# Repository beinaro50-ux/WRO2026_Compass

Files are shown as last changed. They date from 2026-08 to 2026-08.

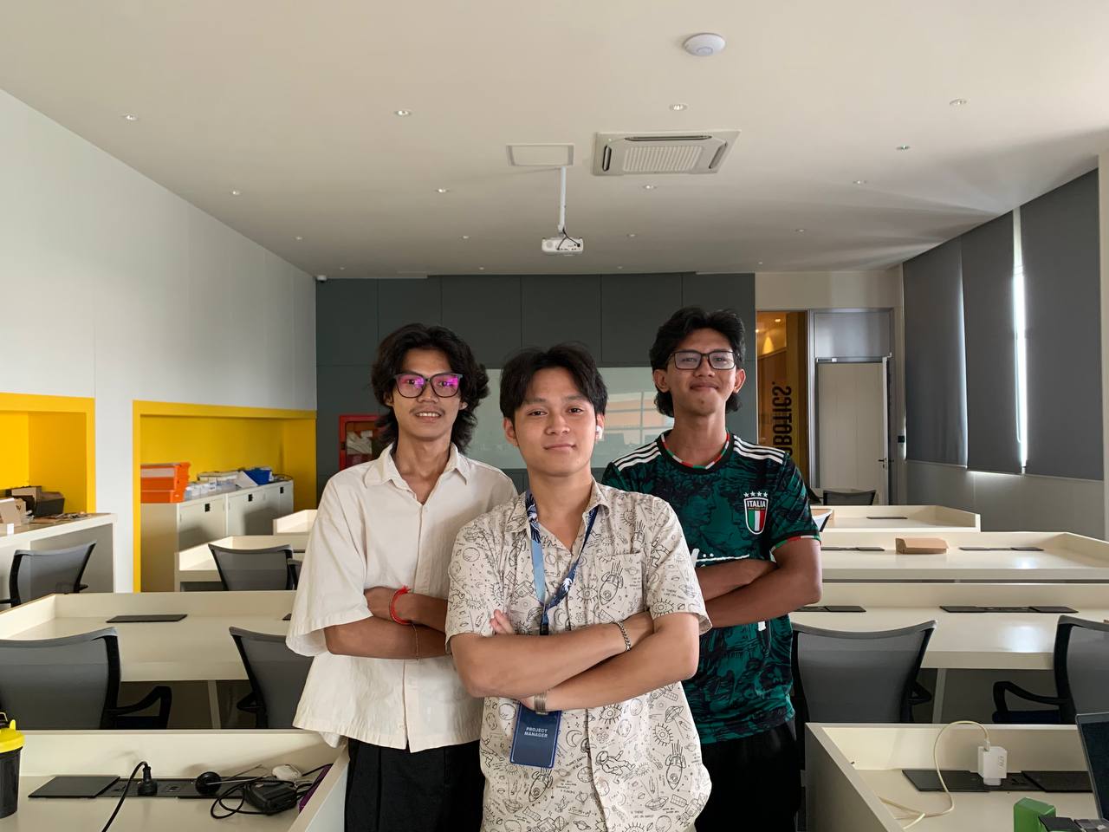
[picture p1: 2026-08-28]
Photo Robot & Team/photo_2026-08-28_14-54-29.jpg

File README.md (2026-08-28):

w# WRO2026_Compass
# Team Compass — WRO 2026 Future Engineers: Self-Driving Cars Challenge

**Country:** Cambodia
**Team Members:** Be Naro, Yeong Vechakasy Sothon, Art Oudom
**Coach:** Taing Liv Min

**GitHub Repository:** `[ TBD — add before the 3-weeks-before-competition submission deadline ]`
**Open Challenge Video:** `[ TBD ]`
**Obstacle Challenge Video:** `[ TBD ]`

---

## Table of Contents
1. [Mobility and Mechanical Design](#1-mobility-and-mechanical-design)
2. [Power and Sensor Architecture](#2-power-and-sensor-architecture)
3. [Software Architecture and Obstacle Strategy](#3-software-architecture-and-obstacle-strategy)
4. [Systems Thinking and Engineering Decisions](#4-systems-thinking-and-engineering-decisions)
5. [Reproducibility and Repository Structure](#5-reproducibility-and-repository-structure)
6. [Photos and Video Demonstrations](#6-photos-and-video-demonstrations)

---

## 1. Mobility and Mechanical Design

### 1.1 Chassis and Drive System
Our chassis is fully **3D-printed in PLA filament**, designed to fit within the 300 × 200 × 300 mm vehicle envelope required by WRO rule 11.1.

The drivetrain is **rear-wheel drive (RWD)**, powered by a single **JGA25-370 DC gear motor** (12V, rated 1360 RPM), driving the rear axle through a two-stage gear reduction:
- A 14 mm pinion gear on the motor output meshes with a 25 mm gear on the driven axle
- This gives an approximate **1.79:1 reduction**

This gearing trades top speed for extra torque and steadier low-speed control, which matters for precise lane-following and parking maneuvers.

### 1.2 Steering Mechanism
Steering is handled by a single **MG996R servo** connected to a steering linkage on the front axle, satisfying WRO rule 11.3 (one steering actuator, front/rear/4WD drive — not a differential/skid-steer base).

| Parameter | Value |
|---|---|
| Length from servo to wheel connector | 75 mm |
| Maximum steering angle | 30° |
| Radius | 75 mm |
| Diameter | 150 mm |
| Turning length (AB) | 39.25 mm |

### 1.3 Diagrams / CAD Views
Robot 


Front side


Back side


Bottom 


### 1.4 Testing and Iteration
We went through **three major chassis redesigns** before arriving at our current layout:

- **Versions 1 & 2:** Placed the RPLiDAR A2M12 at the rear of the vehicle. Limited internal space made it difficult to route wiring and mount the ESP32, L298N driver, and battery cleanly.
- **Version 3 (current):** Relocated the LiDAR to the front of the vehicle and moved the ESP32, motor driver, and battery to the rear. This freed up space around the LiDAR's 360° scanning field and simplified our wiring harness.

We also **raised the camera's mounting height** after early testing showed our original (lower) mounting position caused the camera to miss or misjudge the distance to obstacle pillars. Raising the mount improved our ability to keep pillars clearly framed for detection.

---

## 2. Power and Sensor Architecture

### 2.1 Power System
The vehicle uses a single **12V 3A battery pack** as the primary power source, feeding the ESP32, the DC motor (via the L298N driver), and the steering servo. The servo line is stepped down from 12V through a regulator/transformer before reaching the MG996R (rated 4.8–7.2V).

The **Raspberry Pi 4 is powered independently** from a separate portable USB power bank, isolating its 5V logic supply from motor and servo electrical noise on the 12V line.

### 2.2 Power Budget

| Component | Voltage | Est. Current | Source |
|---|---|---|---|
| Raspberry Pi 4 | 5V (power bank) | ~3A max | Official RPi4 PSU rating |
| ESP32 | 5V (onboard reg.) | ~0.3–0.5A typical | Datasheet typical |
| RPLiDAR A2M12 | 5V | ~0.2–0.3A (core+motor) | Manufacturer spec |
| JGA25-370 DC Motor | 12V | ~0.3A run / ~3A stall | Typical for motor class |
| MG996R Servo | 9V | ~0.5–0.9A / ~2.5A stall | Datasheet typical |

> **Note:** These are datasheet/spec estimates, not yet measured on this specific build. Actual draw should be measured with a multimeter or USB power meter (especially motor and servo under load/stall) before finalizing wiring gauge and battery sizing.

### 2.3 Sensor Suite
- **RPLiDAR A2M12** (360°, 12 m range) — mounted front-facing, providing wall-distance and obstacle-range data used for LiDAR-based wall following.
- **USB webcam (8 MP)** — mounted toward the back of the chassis on a camera stand. Used for pillar color/class detection and lane-position estimation via our trained YOLO model.

### 2.4 Wiring Diagram
The vehicle's electrical system is split into four subsystems on two isolated power domains: a 5V logic/compute domain (Raspberry Pi 4 + sensors) and a 12V power domain (drive motor + servo), bridged by the ESP32 acting as the real-time actuator controller.
Subsystem 1 — Central Control & Vision (5V)
- A dedicated 5V powerbank supplies the Raspberry Pi 4 via USB 3.0 (rated ~3A max draw).
- The USB 2.0 8MP PC camera connects to the Pi 4 via USB 3.0.
- The RPLiDAR A2M12 (5V, ~0.2–0.3A) connects to the Pi 4 via USB.
- This subsystem is intentionally powered independently from the 12V motor/servo domain, isolating the Pi's logic supply from motor electrical noise.
Subsystem 2 — Actuator Control (ESP32). 
- The Raspberry Pi 4 communicates with the ESP32 over a serial link (Tx/Rx), sending high-level driving commands.
- The ESP32 runs on its onboard 5V regulator (~0.3–0.5A).
- The ESP32 outputs: 
  **PWM + H-bridge control signals to the L298N motor driver (Subsystem 3)**
  **PWM signal to the MG996R servo (Subsystem 4)**
  **Shared GND to both subsystems**
  Subsystem 3 — L298N DC Motor Driver (12V high-power)
- A 12V 3A battery feeds the L298N driver board directly ("12V Battery Input").
- The JGA25-370 DC motor connects to the L298N's Motor A output terminals.
- The ESP32 sends a PWM signal (IN1) to the L298N to control motor speed/direction.
- The L298N also exposes a 12V output tap, which is routed onward to Subsystem 4's power converter.
  Subsystem 4 — Servo Subsystem
- The L298N's 12V output feeds a power converter (12V in → 9V out), which steps the battery voltage down to a safe level for the MG996R servo (rated 4.8–7.2V nominal, but run here at ~9V converted power per your table).
- The servo receives PWM control from the ESP32 and shares GND across the system.
- Current draw reference from your spec table: ~0.33A running at 12V, ~0.5–0.9A running at 9V, up to ~2.5A stall.

### 2.5 Calibration
*[ Describe sensor calibration — e.g., camera color thresholds for red/green pillar detection, LiDAR mounting angle offset — once finalized ]*

---

## 3. Software Architecture and Obstacle Strategy

### 3.1 System Architecture
Our software runs on the **Raspberry Pi 4** and is organized into cooperating modules:

- **LiDAR reader** — background thread continuously reading the RPLiDAR A2M12
- **Vision worker** — camera capture plus YOLO model inference
- **State machine** — fuses LiDAR wall-following with camera-based pillar and lane detection to decide speed and steering
- **Serial link** — sends the resulting commands to the ESP32, which drives the DC motor (via L298N) and steering servo in real time

**Flowchart**


### 3.2 Lane Following Strategy
Our primary lane-following signal comes from the **RPLiDAR A2M12**: we calculate the vehicle's distance to the left and right walls from the 360° scan and use a **PID controller** to steer toward the section centerline.

Camera-based lane detection from our YOLO model is layered on top as a **secondary correction signal**, since LiDAR is more robust to lighting changes on the track than a camera alone.

### 3.3 Obstacle (Traffic Sign) Strategy
Our team designed the vehicle's mechanical layout in **Solid Edge** and trained our pillar/lane detection model using **YOLO**. The model detects red and green traffic pillars in the camera frame and classifies them by color.

Per WRO rule 9.19:
- When a **red pillar** is detected ahead, the vehicle steers to keep the pillar on its **right** side.
- When a **green pillar** is detected, the vehicle steers to keep the pillar on its **left** side.

**To be completed before submission:**
- Final training image count and train/validation split
- Key metrics (e.g., mAP, precision/recall)
- PID tuning notes for the wall-following controller, based on physical track testing

## 4. Systems Thinking and Engineering Decisions

### 4.1 Subsystem Interaction Map


That maps how your four subsystems depend on each other: Power feeds all three others directly (amber arrows), Sensors feed raw LiDAR + camera data into Software, and Software sends the final steering/motor commands down to Mobility.

This is the kind of diagram Appendix C Criterion 4 ("Systems Thinking") specifically rewards — it shows you understand the robot as an interconnected system rather than just a parts list. A couple of notes for when you drop this into the README:

- If you want to be even more precise, you could split the single "Power" arrow into three separately-labeled ones (5V line to Pi/sensors, 12V line to motor, 9V converted line to servo) — that would tie directly back into your power budget table and reinforce the two-domain design you documented.
- This diagram pairs well with the ground-domain risk we discussed earlier — you could add a small dashed line or note showing "no shared ground (current risk)" between the Power and Mobility boxes if you want the diagram itself to visually flag that gap, not just the prose.

### 4.2 Key Design Tradeoffs

**Decision 1 — Sensor placement vs. available chassis space:**
Our first two chassis revisions placed the RPLiDAR at the rear of the vehicle, but tight internal space made wiring and component mounting difficult. We chose to redesign (third iteration) and move the LiDAR to the front, trading some rear layout simplicity for a cleaner wiring harness and an unobstructed 360° scan field.

**Decision 2 — ONNX vs. PyTorch for on-board inference:**
Our trained model was exported in both PyTorch (`.pt`) and ONNX (`.onnx`) formats. We chose to deploy the **ONNX** version on the Raspberry Pi 4, since ONNX Runtime is significantly faster and lighter-weight for inference on limited onboard compute than running the full PyTorch framework — this matters for keeping our control loop running at a consistent rate during a live round.

### 4.3 Risks and Mitigations

| Risk | Mitigation |
|---|---|
| Serial link between RPi4 and ESP32 drops mid-run | ESP32 firmware includes a watchdog timer that force-stops the motor if no command is received within 300ms |
| Servo over-voltage (MG996R rated 4.8–7.2V, battery is 12V) | Servo power is stepped down through a separate regulator before reaching the servo (exact output voltage to be confirmed and documented) |
| Camera mounted too low to reliably detect pillars | Identified during testing; camera mount height was raised in our third chassis revision |
| Limited internal chassis space causing wiring/component conflicts | Redesigned chassis three times, relocating LiDAR to the front and ESP32/motor driver/battery to the rear |

### 4.4 Version History
- **Version 1:** Initial chassis with LiDAR mounted at the rear — space too tight for clean wiring.
- **Version 2:** Adjusted internal layout, LiDAR remained at the rear — still constrained; camera mounted too low for reliable pillar detection.
- **Version 3 (current):** LiDAR relocated to the front; ESP32, L298N, and battery relocated to the rear; camera mount height raised.

We are going to fix some of this robot machinal due to it contains some stress from steering wheel and the battery do not have enough power to 

---

## 5. Reproducibility and Repository Structure

### 5.1 Planned Repository Layout

```
/src              — vehicle control source code
                    (main.py, config.py, lidar_module.py,
                     vision_module.py, state_machine.py, serial_link.py)
/esp32_firmware   — ESP32 motor/servo controller firmware
/models           — trained YOLO model files (ONNX export used on-vehicle)
/cad              — 3D-printable chassis files
/schematics       — wiring diagrams, power budget
/media            — vehicle photos (6 views) and team photo
```

> **Status:** Repository is not yet public. Per WRO rules, we will follow the required commit timing (first commit ≥ 2 months before competition containing at least 1/5 of final code, second ≥ 1 month before, third ≥ 2 weeks before) and add the public URL above before the submission deadline (3 weeks before competition).

### 5.2 Build Instructions Summary
**Software section** 
We use a pretrained YOLO model (not custom-trained on our own pillar dataset) rather than collecting and labeling our own training set. Our own engineering work here was in configuring the model's confidence threshold — tuning the minimum detection confidence YOLO needs before we trust a detection, to balance:

Missed detections (threshold too high → pillar not seen in time to react)
False positives (threshold too low → reacting to noise or irrelevant objects)

Why we chose this approach over training our own model:
Training a custom YOLO model requires collecting and labeling a large dataset of red/green pillar images across different lighting conditions, distances, and angles — a significant time investment. Using a pretrained model with tuned thresholds let us get a working detection pipeline running quickly at the tradeoff of relying on YOLO's general-purpose object classes rather than a model purpose-built to recognize WRO pillars specifically.

To be completed before submission:

The exact confidence threshold value we settled on, and the reasoning/testing behind it (e.g., "we tested 0.5, 0.6, 0.7 and found 0.6 gave the best balance of X vs Y")
How color (red vs. green) is actually determined once YOLO flags a detection — e.g., pixel-color sampling within the bounding box (this connects to your calibration section, which is also still pending)
Any measured detection accuracy/reliability from track testing

**Hardware Section**
The mechanical design phase took approximately two weeks, followed by roughly nine days of physical assembly.

A key challenge emerged during this process: our initial chassis design was built to accommodate only three hardware components. Partway through assembly, some of those original components broke and had to be replaced with larger alternatives — which no longer fit within the space our first design had allocated. This forced us to revisit our internal layout and rework the chassis to accommodate the new component sizes, rather than simply swapping parts in place.

This experience directly informed our decision to design for extra internal clearance in later chassis revisions (see Version History, Section 4.4), rather than sizing the chassis tightly around the exact components on hand — a lesson that also shaped our approach to component selection going forward, favoring some margin for hardware substitutions over a minimal-footprint design.

## 6. Photos and Video Demonstrations

### 6.1 Required Photos
- Team photo
  
  
- Front side
  
- Back Side
  
- Above
  
- Bottom
  
- Left Side
  
- Right Side
  

### 6.2 Video Demonstrations
Per WRO documentation rules, one YouTube video (public or unlisted/link-accessible) is required for **each** challenge, with a driving demonstration segment at least 30 seconds long.

- **Open Challenge video:** `
https://youtu.be/FjARO7ldRJU

- **Obstacle Challenge video:** `
https://youtu.be/bZQAO0thAtA

---

*This documentation follows the WRO 2026 Future Engineers General Rules, Section 7 (Engineer's Documentation on GitHub) and Appendix C (Engineering Journal Evaluation).*

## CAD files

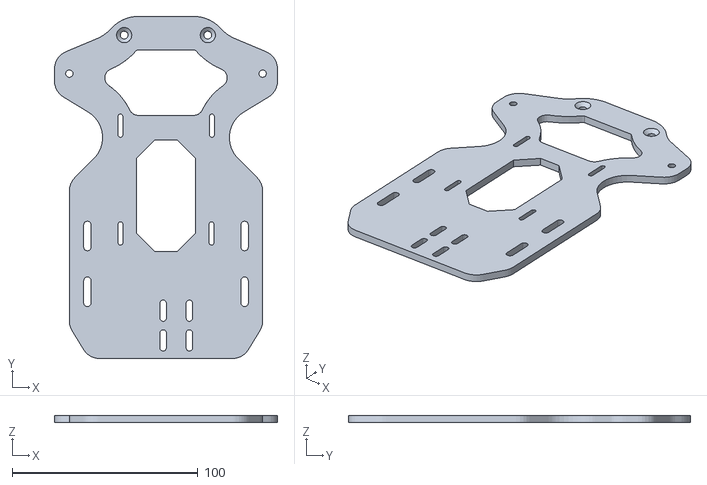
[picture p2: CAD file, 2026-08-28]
Model/Chassis 1st floor.stl
120.0 x 184.0 x 4.00

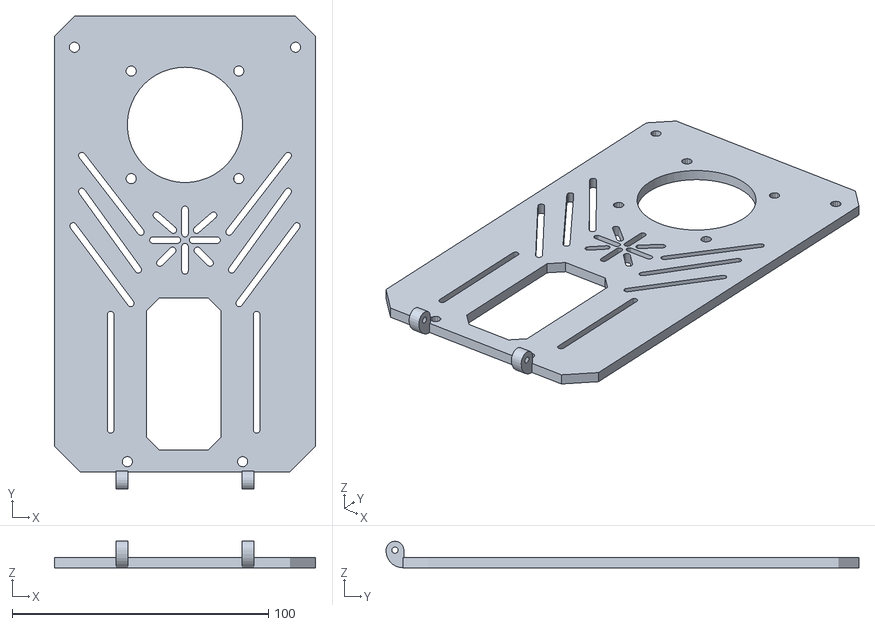
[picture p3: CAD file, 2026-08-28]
Model/Platform 3rd floor .stl
102.0 x 184.7 x 10.4

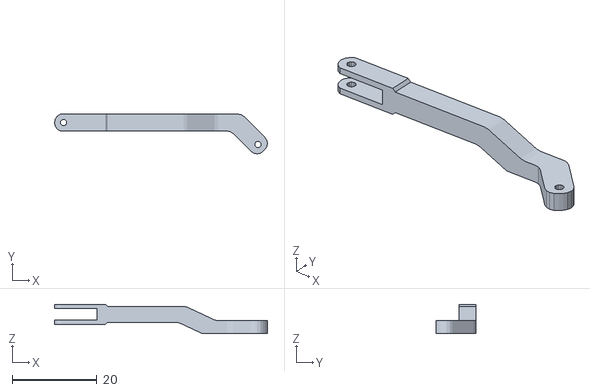
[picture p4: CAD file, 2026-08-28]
Model/Steering wheel (left).stl
50.2 x 9.37 x 6.95

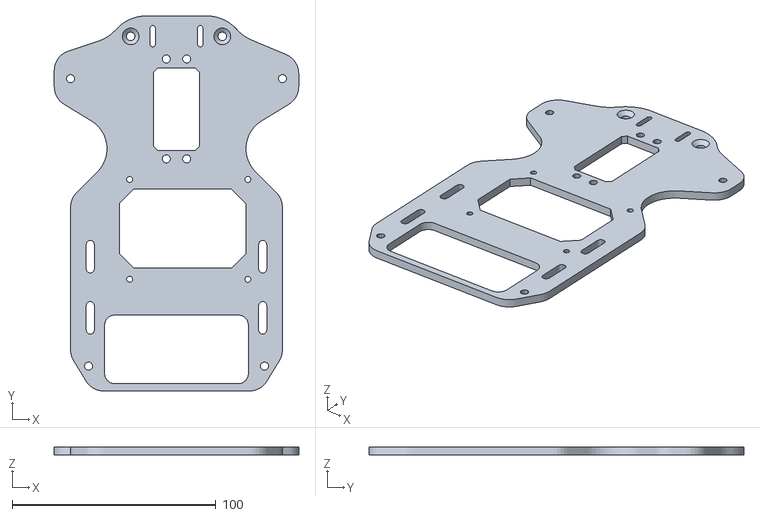
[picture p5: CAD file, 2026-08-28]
Model/Chassis 2rd floor.stl
120.0 x 184.0 x 4.00

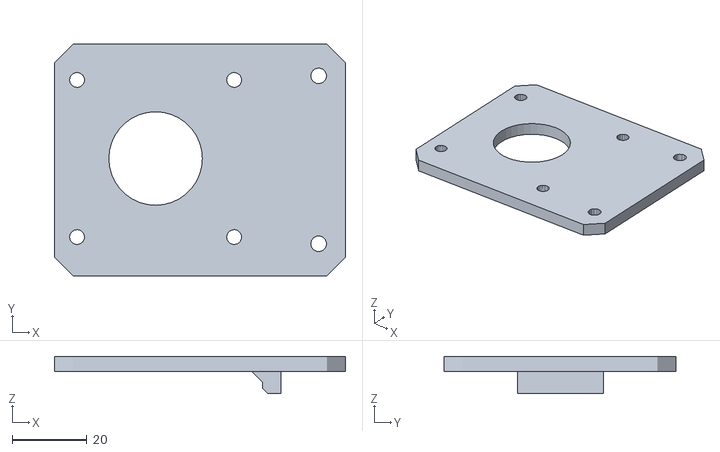
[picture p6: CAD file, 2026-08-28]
Model/RPLidar platform.stl
77.8 x 62.0 x 10.0

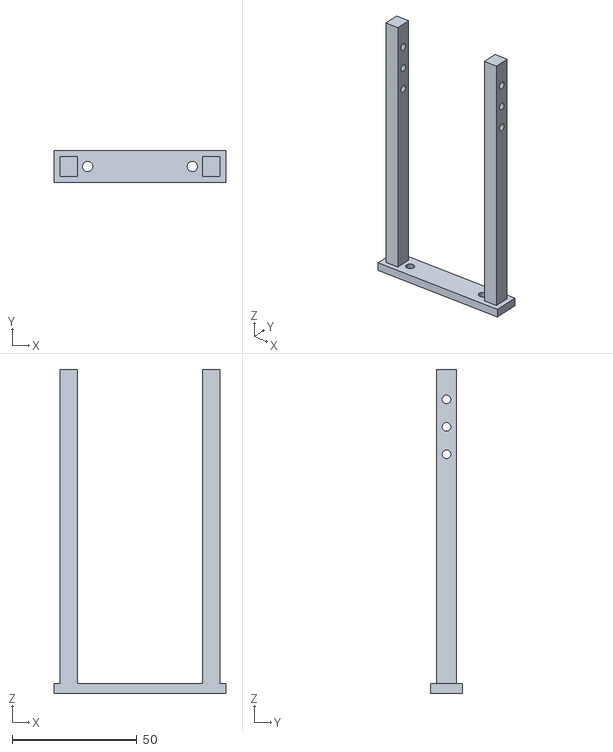
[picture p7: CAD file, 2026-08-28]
Model/camerastanding.stl
69.0 x 13.0 x 130.0

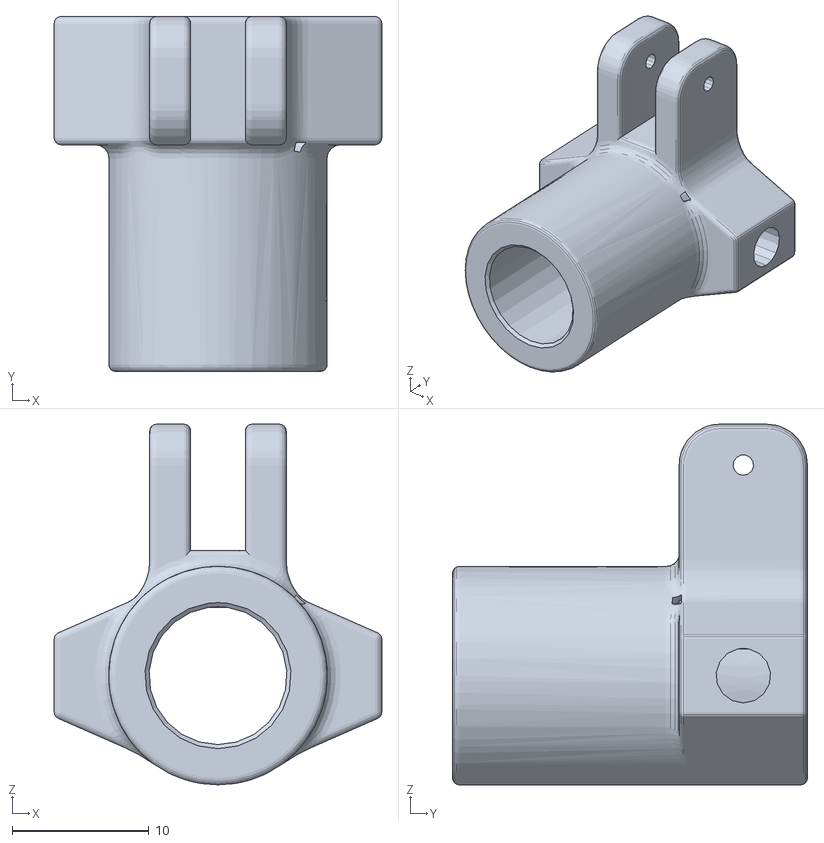
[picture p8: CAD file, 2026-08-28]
Model/Hub.stl
24.0 x 26.0 x 26.4

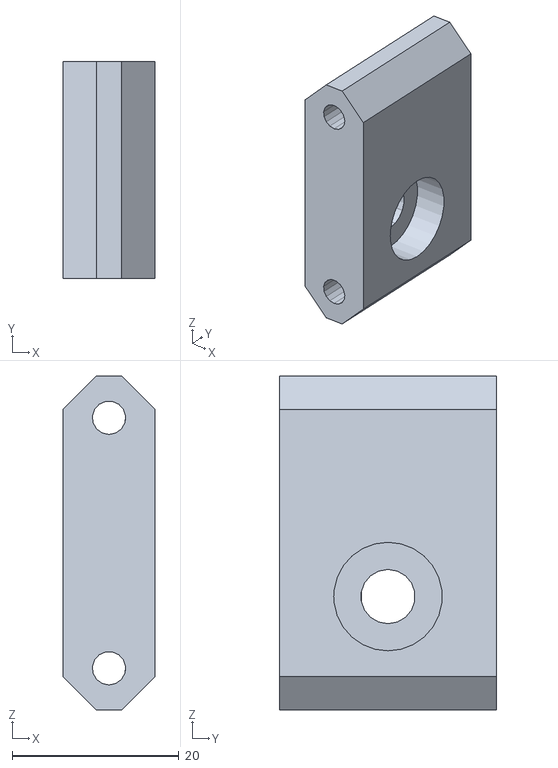
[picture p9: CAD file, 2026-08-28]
Model/BackWheel Mount.stl
11.0 x 26.0 x 40.0

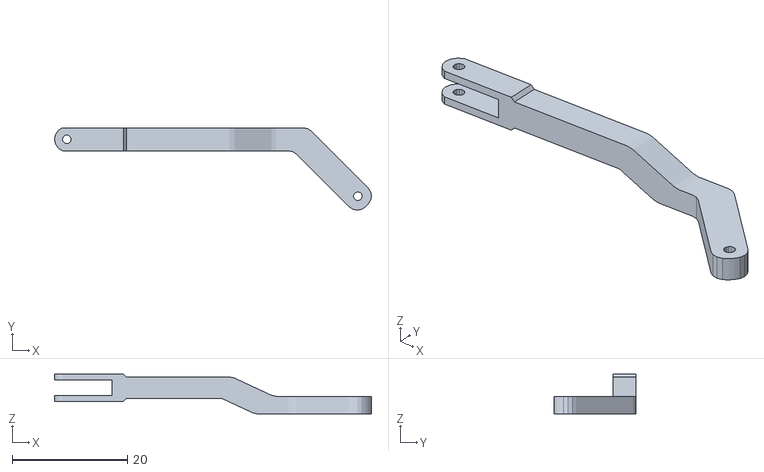
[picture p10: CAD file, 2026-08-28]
Model/Steering wheel (right).stl
55.1 x 14.3 x 6.95

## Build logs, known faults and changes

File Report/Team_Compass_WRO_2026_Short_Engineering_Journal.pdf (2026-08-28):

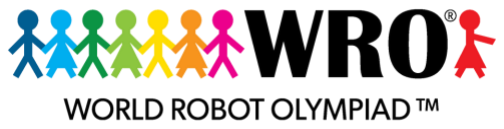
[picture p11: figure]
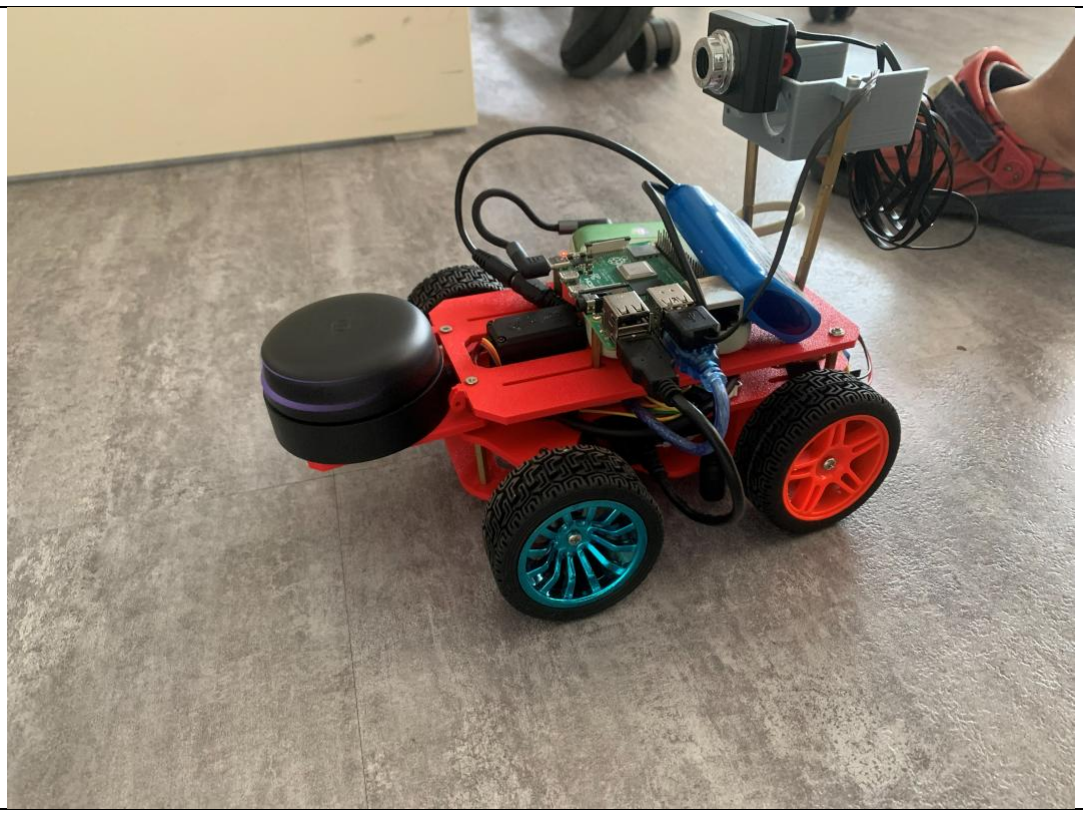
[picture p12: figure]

Team Compass | WRO 2026 Future Engineers
Team name | Compass
Team number | FE-002
Team members | Be Naro, Yeong Vechakasy Sothon, Art Oudom
Team coach | Taing Ly Min
Robotic set | Self-assembled set
Weight | 1.10kg
Size | 290× 175 × 180 mm
Building materials | Fully 3D-printed PLA chassis and mechanical parts
Controllers | Raspberry Pi 4, ESP32, L298N
Battery | 12V, 3A battery pack; Raspberry Pi 4 uses separate USB power bank
Sensors | 1× RPLiDAR A2M12, 1× 8 MP USB webcam
Motors | 1× JGA25-370 DC gear motor, 1× MG996R servo
Pneumatic system | Not used
Spare parts | Battery x3, Battery charger x2, Screw driver set, Nuts x5, glue stick x1, power bank x1,
Programming Environment & language | Python, YOLO, ESP32 firmware
Drive & steering | RWD; single MG996R front steering servo; max steering angle 30°
Gear reduction | 14 mm pinion → 25 mm gear; ≈1.79:1 reduction
Steering geometry | 75 mm radius; 150 mm diameter; AB = 39.25 mm
Design iteration | 3 chassis designs; LiDAR moved rear → front; electronics/battery moved to rear; camera mount raised after testing
LiDAR function | 360° wall-distance and obstacle detection; primary lane/wall-following signal
Camera function | YOLO detects red/green pillars and provides secondary lane-position correction
Control algorithm | PID lane following + state machine combining LiDAR and vision
Red pillar | Keep pillar on the right
Green pillar | Keep pillar on the left
GitHub / Videos | https://youtu.be/hSMSpn8qdMk

Picture of the robot with start and stop bottom

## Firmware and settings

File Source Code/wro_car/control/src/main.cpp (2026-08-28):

#include <Arduino.h>

// Motor
#define IN1 26
#define IN2 27
#define ENA 25
#define MOTOR_CHANNEL 0
#define MOTOR_FREQ 5000
#define MOTOR_RES 8
#define PWM_MIN 150
#define PWM_MAX 255

// Servo (manual PWM, no library, separate channel/timer from motor)
#define SERVO_PIN 19
#define SERVO_CHANNEL 4
#define SERVO_FREQ 50
#define SERVO_RES 16
#define SERVO_MIN_US 500
#define SERVO_MAX_US 2500

// Encoder
#define ENC_A 34
#define ENC_B 35

volatile long encoderTicks = 0;
void IRAM_ATTR encoderISR() {
  int a = digitalRead(ENC_A);
  int b = digitalRead(ENC_B);
  encoderTicks += (a == b) ? 1 : -1;
}

String inputBuffer = "";
unsigned long lastFeedback = 0;
const unsigned long FEEDBACK_INTERVAL_MS = 50;

void motorStop() {
  digitalWrite(IN1, LOW);
  digitalWrite(IN2, LOW);
  ledcWrite(MOTOR_CHANNEL, 0);
}

void setMotor(int throttle) {
  throttle = constrain(throttle, -255, 255);
  if (throttle == 0) { motorStop(); return; }
  int mag = abs(throttle);
  int pwm = constrain(map(mag, 1, 255, PWM_MIN, PWM_MAX), PWM_MIN, PWM_MAX);
  if (throttle > 0) { digitalWrite(IN1, HIGH); digitalWrite(IN2, LOW); }
  else              { digitalWrite(IN1, LOW);  digitalWrite(IN2, HIGH); }
  ledcWrite(MOTOR_CHANNEL, pwm);
}

void setServoAngle(int angle) {
  angle = constrain(angle, 0, 360);
  int pulse_us = map(angle, 0, 360, SERVO_MIN_US, SERVO_MAX_US);
  uint32_t maxDuty = (1UL << SERVO_RES) - 1;
  uint32_t duty = (uint32_t)(((float)pulse_us / 20000.0f) * maxDuty);
  ledcWrite(SERVO_CHANNEL, duty);
}

void processCommand(String cmd) {
  cmd.trim();
  if (cmd.length() < 3) return;
  char type = cmd.charAt(0);
  String value = cmd.substring(2);

  if (type == 'M') {
    int throttle = value.toInt();
    setMotor(throttle);
    Serial.print("AM,"); Serial.println(throttle);
  } else if (type == 'S') {
    int angle = value.toInt();
    setServoAngle(angle);
    Serial.print("AS,"); Serial.println(angle);
  }
}

void setup() {
  Serial.begin(115200);

  pinMode(IN1, OUTPUT);
  pinMode(IN2, OUTPUT);
  ledcSetup(MOTOR_CHANNEL, MOTOR_FREQ, MOTOR_RES);
  ledcAttachPin(ENA, MOTOR_CHANNEL);

  ledcSetup(SERVO_CHANNEL, SERVO_FREQ, SERVO_RES);
  ledcAttachPin(SERVO_PIN, SERVO_CHANNEL);
  setServoAngle(90);

  pinMode(ENC_A, INPUT);
  pinMode(ENC_B, INPUT);
  attachInterrupt(digitalPinToInterrupt(ENC_A), encoderISR, CHANGE);

  motorStop();
  Serial.println("READY");
}

void loop() {
  while (Serial.available() > 0) {
    char c = Serial.read();
    if (c == '\n') { processCommand(inputBuffer); inputBuffer = ""; }
    else inputBuffer += c;
  }

  unsigned long now = millis();
  if (now - lastFeedback >= FEEDBACK_INTERVAL_MS) {
    lastFeedback = now;
    Serial.print("ENC,");
    Serial.println(encoderTicks);
  }
}

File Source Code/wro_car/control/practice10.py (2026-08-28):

#!/usr/bin/env python3
"""
WRO Future Engineers 2026 - Bench Test & Teleop Dashboard
=========================================================
"""
import argparse
import json
import logging
import math
import os
import threading
import time
from dataclasses import dataclass, field

# Keep the BLAS libraries single-threaded. numpy/OpenCV spawning their own
# thread pools on top of our threads is a common source of instability and
# jitter on a Raspberry Pi. Must be set before numpy/cv2 are imported.
os.environ.setdefault("OPENBLAS_NUM_THREADS", "1")
os.environ.setdefault("OMP_NUM_THREADS", "1")
os.environ.setdefault("MKL_NUM_THREADS", "1")
os.environ.setdefault("NUMEXPR_NUM_THREADS", "1")
os.environ.setdefault("OPENCV_LOG_LEVEL", "ERROR")

import cv2
import numpy as np
import flask.cli
from flask import Flask, Response, jsonify, render_template_string, request

# cv2.dnn's forward pass otherwise grabs every core in its own thread pool for
# the duration of each inference call. On the Pi 4B's 4 cores that starves the
# LiDAR thread of scheduling time long enough for the OS serial buffer to
# overflow ("Too many bytes in the input buffer ... Cleaning buffer"), forcing
# an RPLidar rescan. Leaving 1-2 cores free keeps that thread - and the camera
# capture thread and the Flask dashboard - responsive while inference runs.
cv2.setNumThreads(2)

# ============================================================================
# SECTION 1 - TUNABLE PARAMETERS
# ============================================================================

# ---------------------------------------------------------------- 1.1 chassis
WHEELBASE_MM = 125.0             # front axle centre to rear axle centre
FRONT_TRACK_MM = 140.0           # left to right front wheel centre
REAR_TRACK_MM = 125.0            # left to right rear wheel centre
WHEEL_DIAMETER_MM = 68.0         # measured with the tyre fitted, not the rim
ROBOT_LENGTH_MM = 250.0          # used only to sanity-check rule 11.1 / 9.17
ROBOT_WIDTH_MM = 170.0           # limit is 300 x 200 mm, height 300 mm

# ------------------------------------------------------- 1.2 steering servo
STEER_CENTRE_CMD = 100           # servo command that points the wheels straight
STEER_CMD_MIN = -140                # servo command at full left lock
STEER_CMD_MAX = 140              # servo command at full right lock
STEER_MAX_LEFT_DEG = 30.0        # MEASURE: real wheel angle at full left
STEER_MAX_RIGHT_DEG = 30.0        # MEASURE: real wheel angle at full right

# ---------------------------------------------------------- 1.3 drive motor
DRIVE_CMD_MAX = 255              # ESP32 accepts -255..255
TICKS_PER_WHEEL_REV = 2000       # MEASURE: roll the wheel 10 turns by hand,
THROTTLE_POLARITY = -1           # set to -1 if a positive command drives the
                                 # car backwards. Applied only in set_drive(),

# Slew-rate limits.
THROTTLE_RAMP_PER_SEC = 400.0    # throttle units per second (0->255 in ~0.6 s)
STEER_RAMP_PER_SEC = 180.0       # degrees per second
RAMP_LOOP_HZ = 50                # how often the ramp loop ticks

# ----------------------------------------------------------- 1.4 serial link
SERIAL_PORT = "/dev/esp32"       # or COM5 on Windows
SERIAL_BAUD = 115200
SERIAL_RECONNECT_SEC = 2.0
COMMAND_WATCHDOG_SEC = 0.5       # stop the motor if no command arrives in time

# ---------------------------------------------------------------- 1.5 camera
# "/dev/webcam" is a stable symlink, not a real device - create it with a udev
# rule keyed to the webcam's vendor:product ID so it does not move to
# /dev/video1 after a reboot or a different USB port. Numeric index 0 also
# works but is not reliable once a second camera or capture device is plugged
# in.
CAMERA_DEVICE = "/dev/webcam"    # or an integer index such as 0
FRAME_WIDTH = 640
FRAME_HEIGHT = 480               # a mini USB 2.0 webcam is usually MJPG-only
                                 # at this size; raw YUYV caps out near 5 fps
JPEG_QUALITY = 70                # lower = less WiFi bandwidth on the Pi

CAMERA_HEIGHT_MM = 160.0         # lens centre above the mat
CAMERA_TILT_DEG = 0.0            # positive = tilted down toward the mat
CAMERA_FOCAL_PX = 600.0          # pinhole focal length in pixels

# ------------------------------------------------------- 1.6 pillar geometry
PILLAR_WIDTH_MM = 50             # rule 13.19: 50 x 50 x 100 mm
PILLAR_HEIGHT_MM = 100
PILLAR_ASPECT_NOMINAL = PILLAR_WIDTH_MM / PILLAR_HEIGHT_MM   # 0.5

# ------------------------------------------------------ 1.7 detection backend
DETECTION_BACKEND = "auto"

# ---------------------------------------------------------- 1.8 ONNX detector
# Resolved next to this script, not the process's working directory, so this
# still finds best.onnx when launched by a systemd service or a start button
# instead of a manually cd'ed-into terminal (rule 9.10 / 9.11).
ONNX_MODEL_PATH = os.path.join(os.path.dirname(os.path.abspath(__file__)), "best.onnx")
ONNX_INPUT_SIZE = 416            # confirmed from best.onnx's own input tensor
                                 # (images: [1,3,416,416]) - must always match
                                 # whatever imgsz a re-export uses
ONNX_CONF_THRESHOLD = 0.45
ONNX_NMS_IOU_THRESHOLD = 0.45
# Detection runs on its own thread at whatever pace inference allows (see
# Camera._detect_loop) rather than every Nth captured frame, so the video
# stream never stalls waiting for a slow forward pass.
ONNX_CLASS_NAMES = ["greenbox", "redbox", "xparking"]
CLASS_NAME_TO_COLOUR = {
    "greenbox": "GREEN",
    "redbox": "RED",
}

# ----------------------------------------------------------- 1.9 HSV detector
# Minimum value (brightness) set to 100 to completely block black walls!
HSV_RED_RANGES = [((0, 120, 100), (10, 255, 255)), ((170, 120, 100), (179, 255, 255))]
HSV_GREEN_RANGE = ((40, 120, 100), (85, 255, 255))
HSV_MORPH_KERNEL = 5             # noise clean-up kernel, odd numbers only
HSV_MIN_AREA_PX = 300            # reject specks
HSV_MAX_AREA_PX = 150000         # INCREASED: detect closer/larger boxes
HSV_MIN_ASPECT = 0.25            # a pillar is 0.5 wide/high; allow for angle
HSV_MAX_ASPECT = 0.90
RULEBOOK_RED_RGB = (238, 39, 55)
RULEBOOK_GREEN_RGB = (68, 214, 44)

# ----------------------------------------------------------------- 1.10 LiDAR
LIDAR_PORT = "/dev/rplidar"
LIDAR_BAUD = 256000              # RPLidar A2M12 default
LIDAR_HEIGHT_MM = 80.0           # mounted at the nose of the chassis
LIDAR_RECONNECT_SEC = 2.0

LIDAR_FRONT_DEG = 0              # which raw LiDAR angle points at the nose
LIDAR_ANGLE_CW = True            # True if raw angles grow clockwise from above
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
